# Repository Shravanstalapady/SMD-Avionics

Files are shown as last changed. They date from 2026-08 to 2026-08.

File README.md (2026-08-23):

# SMD-Avionics-PCB
# Sounding Rocket Avionics System

A complete avionics package for high-altitude sounding rockets, featuring dual redundancy in barometric sensing, real-time GPS/LoRa telemetry, and programmable pyro firing/servo control.

## Overview

This project implements a two-board avionics system for sounding rocket applications:

- **Flight Controller Board**: RP2350B-based main computer with integrated sensors and communication systems
- **Power Distribution Board**: Regulated power delivery with current monitoring and fault protection

The system is capable of logging sensor data to onboard storage, transmitting telemetry via LoRa, determining apogee via dual barometers, and firing pyro charges or deploying parachutes via servo control.



---

##  Hardware Architecture

### Flight Controller Board 

**Main Processor**
- Raspberry Pi RP2350B (QFN-80, dual-core ARM Cortex M33)
- 32 MHz crystal oscillator with load capacitors
- QSPI flash storage (W25Q128JVSIQ - 128Mb NOR flash)

**Inertial Measurement Unit (IMU)**
- LSM6DSO32 6-axis accelerometer + gyroscope (SPI interface)
- 3-axis acceleration and rotation rate measurement
- Can be used for apogee detection via vertical acceleration

**Barometric Sensors (Dual Redundancy)**
- Primary: BMP390 (SPI interface) - 300-1100 hPa range
- Secondary: MS5611 (I2C interface) - High altitude capable
- Cross-checked for data integrity and fallback capability

**GNSS/Positioning**
- L89HAS90 multi-constellation receiver
  - GPS, GLONASS, BeiDou, Galileo, IRNSS, QZSS support
  - 3D fix output, UTC time sync
  - External antenna via UFL connector

**Telemetry & Long-Range Communication**
- SX1262 LoRa module (868 MHz ISM band)
- SPI interface to MCU
- Real-time data transmission during flight

**Pyro & Servo Control**
- 4x pyro firing channels (continuity-enabled)
  - TLP281-4 optocouplers for isolation
  - IRLR7843 MOSFETs for power switching
  - continuity-check LEDs
- 2x servo PWM output channels
- 10kΩ pull-up resistors on signal lines

**Onboard Storage**
- SD card socket (QSPI quad mode capable)
- Data logging to microSD for black-box recording
- Shared SPI bus with accelerometer

**Interface & Debug**
- USB Type-C connector (CX90M-16P) for programming
- SWD debug header (SM03B-SRSS)
- Active piezo buzzer for audible feedback (GPIO control)
- 2x ARM debug LEDs (APT2012MGC, R0603 current limiting)
- 3x test points for oscilloscope probing (TP1-TP3)

**I2C & SPI Buses**
- I2C0: INA260 current monitor, Accelerometer(10kΩ pullups)
- SPI0: Primary barometer
- SPI1: SD card, MS5611
- QSPI: Flash memory

---

### Power Distribution Board (Main_FC_power_circuitary)

**Primary Buck Converter**
- TPS5450DDAR 5A adjustable regulator
  - Input: +BATT (Li-Po battery recommended)
  - Output: +5V at up to 5A
  - PA4343.153NLT inductor
  - Soft-start to limit inrush current

**Secondary Buck Converter**
- TLV62569PDDCR high-efficiency step-down
  - Input: +5V from primary converter
  - Output: +3.3V or other regulated voltage
  - Optimized for efficency.

**Current Monitoring**
- INA260AIPWR integrated power monitor
  - Measures input current and voltage in real-time
  - I2C interface to flight controller
  - Essential for battery health monitoring and power budgeting
  - Programmable alerts via ALERT pin

**Headers & Distribution**
- Multiple headers for connecting payloads
- +5V rail
- +5High rail
- +3.3V rail  
- Ground distribution (critical for low-impedance GND return)
- XT60 connector for external power
- Debug LEDs (3x) indicating power rail status

---

##  Interface Pinouts & Connectors

### Flight Controller - Key Signals

**GPS/GNSS (L89HAS90)**
- UART: RXD, TXD (async serial 9600 baud typical)
- 1PPS output for timing sync
- External antenna (RP-SMA via UFL)

**LoRa (SX1262)**
- SPI: MOSI, MISO, SCK, CS
- Control: DIO1, DIO2, RST, BUSY
- GPIO: TXEN, RXEN (optional Tx/Rx control)

**Servo Outputs**
- 2x 3-pin JST-PH headers (servo 1, servo 2)
  - Pin 1: +5V
  - Pin 2: PWM signal
  - Pin 3: GND

**Pyro Channels**
- 4x WAGO 2-pin push connectors (pyro 1-4 shared across 2 connectors)
- Electrical continuity check via onboard LEDs
- Fires on MCU GPIO command

**Debug/Serial**
- USB Type-C for programming & serial console
- SWD header (SWCLK, SWD, GND, 3.3V)

**Power Input**
- XT60 main battery connector
- +BATT and GND distribution rails between the two boards
  
**JST VH**
- Connect Power Board to Flight Computer Board
- +5, +3.3, +5H Power Rails, and data from INA Current Sensor is sent over.

---

##  Electrical Specifications

| Parameter | Value | Notes |
|---|---|---|
| **Battery Input** | 3S-4S Li-Po (11.1V - 14.8V nominal) | Connector: XT60 |
| **Board to board connectors** | 10A max per pin | Connector: JST VH |
| **+5V Rail** | 5A max @ 5V | Primary buck converter |
| **+3.3V Rail** | 2A max @ 3.3V | Secondary buck converter |
| **+1.1V Rail** | Internal only | For Rp2350 internal circuitary |
| **Temperature Range** | -40°C to +85°C | Component rated range |
| **SD Card Voltage** | 3.3V | Shared with MCU I/O |
| **LoRa Frequency** | 868 MHz ISM | Region-dependent; requires license compliance |
| **USB Power** | 500 mA max | For programming only; battery required for flight |

---

##  Features & Capabilities

### Sensor Capabilities
-  Dual redundant barometric altitude measurement  
-  6-axis IMU (acceleration + rotation rates)  
-  Multi-constellation GNSS positioning  
-  Real-time telemetry downlink (LoRa)  
-  Onboard data logging to SD card  

### Control & Firing
-  4 programmable pyro firing channels  
-  2 servo control outputs (PWM)  
-  Continuity monitoring on each pyro channel  
-  Optocoupler isolation for pyro firing  

### Power Management
-  Real-time current monitoring  
-  Multiple independent regulated rails  
-  Battery voltage monitoring  

### Interface & Diagnostics
-  USB programming & serial console  
-  SWD JTAG debug port  
-  Onboard status LEDs  
-  Piezo buzzer feedback  
-  Test points for scope probing  

---

##  Bill of Materials Summary

### Flight Controller Board
- **Microcontroller**: 1x RP2350B QFN-80
- **Sensors**: 2x barometers, 1x IMU, 1x GPS, 1x LoRa module
- **Power**: 2x buck converters, 20+ filtering capacitors
- **Discrete**: 30+ resistors, 10x diodes, 2x MOSFETs, 2x optocouplers
- **Connectors**: USB-C, SWD header, servo headers, pyro WAGO connectors, SD card socket
- **Total Components**: ~150 parts

### Power Distribution Board
- **Regulators**: TPS5450, TLV62569, INA260 current monitor
- **Input Protection**: Schottky diodes, XT60 connector
- **Debug**: 3x status LEDs with current-limiting resistors
- **Connectors**: Battery input, XT60 main output, JST VH
- **Total Components**: ~40 parts

Full BOM available in PDF schematics (see `/BOM` section).

---

##  Component Datasheets

Key datasheets for reference:
- **RP2350**: https://datasheets.raspberrypi.com/rp2350/rp2350-datasheet.pdf
- **BMP390**: https://www.bosch-sensortec.com/media/boschsensortec/downloads/datasheets/bst-bmp390-ds002.pdf
- **MS5611**: https://www.te.com/commerce/DocumentDelivery/DDEController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
- **LSM6DSO32**: https://www.st.com/content/st_com/en/products/motion-sensors/inemo-inertial-measurement-units/lsm6dso32.html
- **SX1262**: https://semtech.my.salesforce.com/sfc/p/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
- **L89HAS90**: https://www.u-blox.com/en/product/l89-high-precision-gnss-module





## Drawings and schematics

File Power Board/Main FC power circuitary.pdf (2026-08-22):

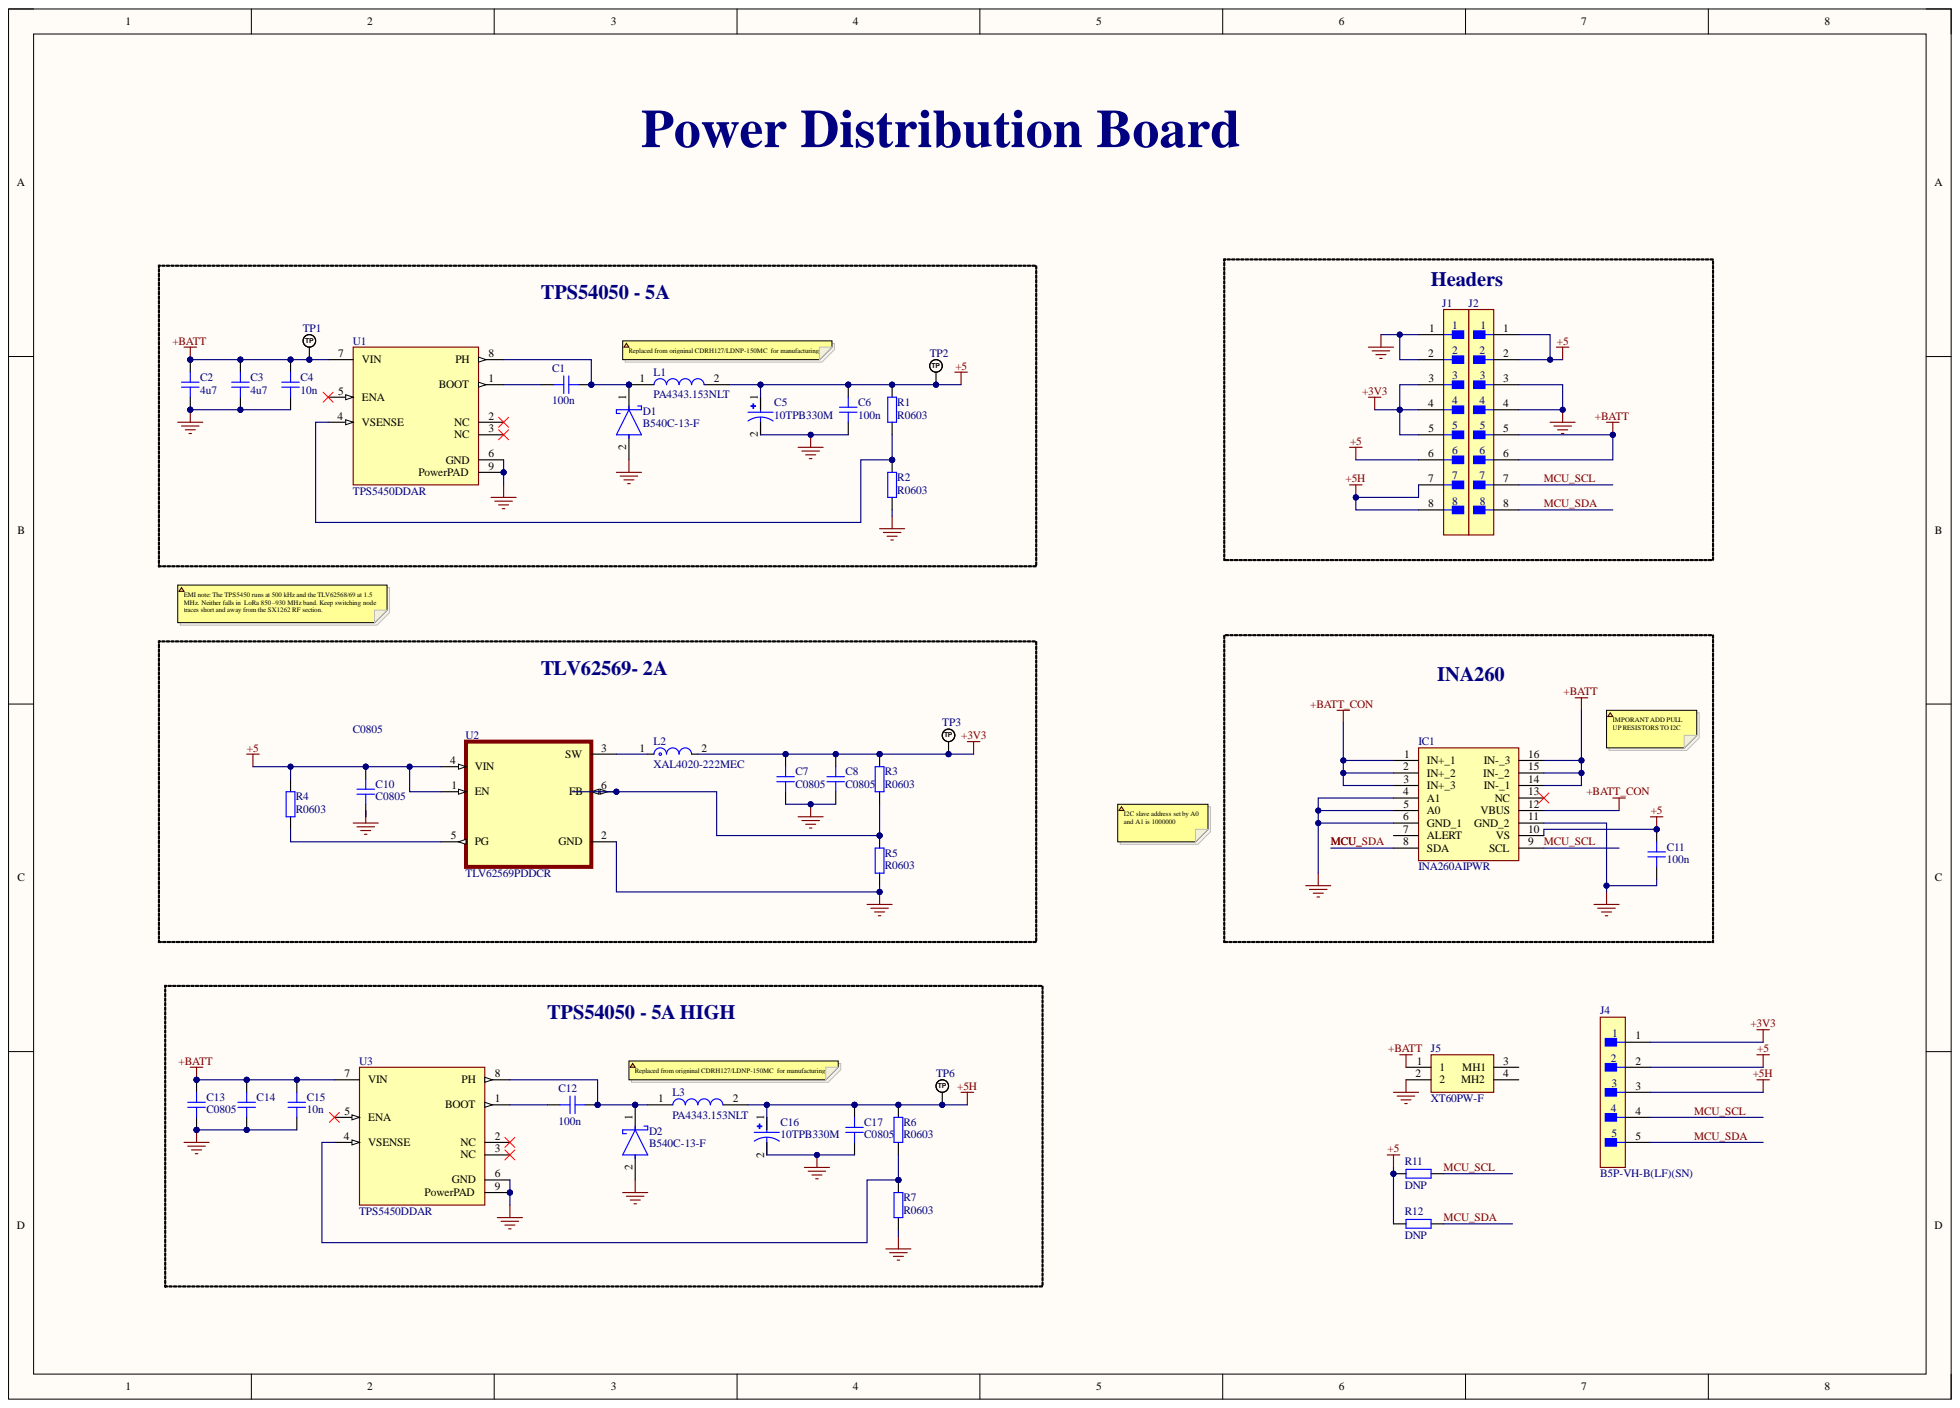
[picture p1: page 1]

Replaced from origninal CDRH127/LDNP-150MC for manufacturing

ENA 5

EMI note: The TPS5450 runs at 500 kHz and the TLV62568/69 at 1.5
MHz. Neither falls in LoRa 850 –930 MHz band. Keep switching node
traces short and away from the SX1262 RF section.

I2C slave address set by A0
and A1 is 1000000

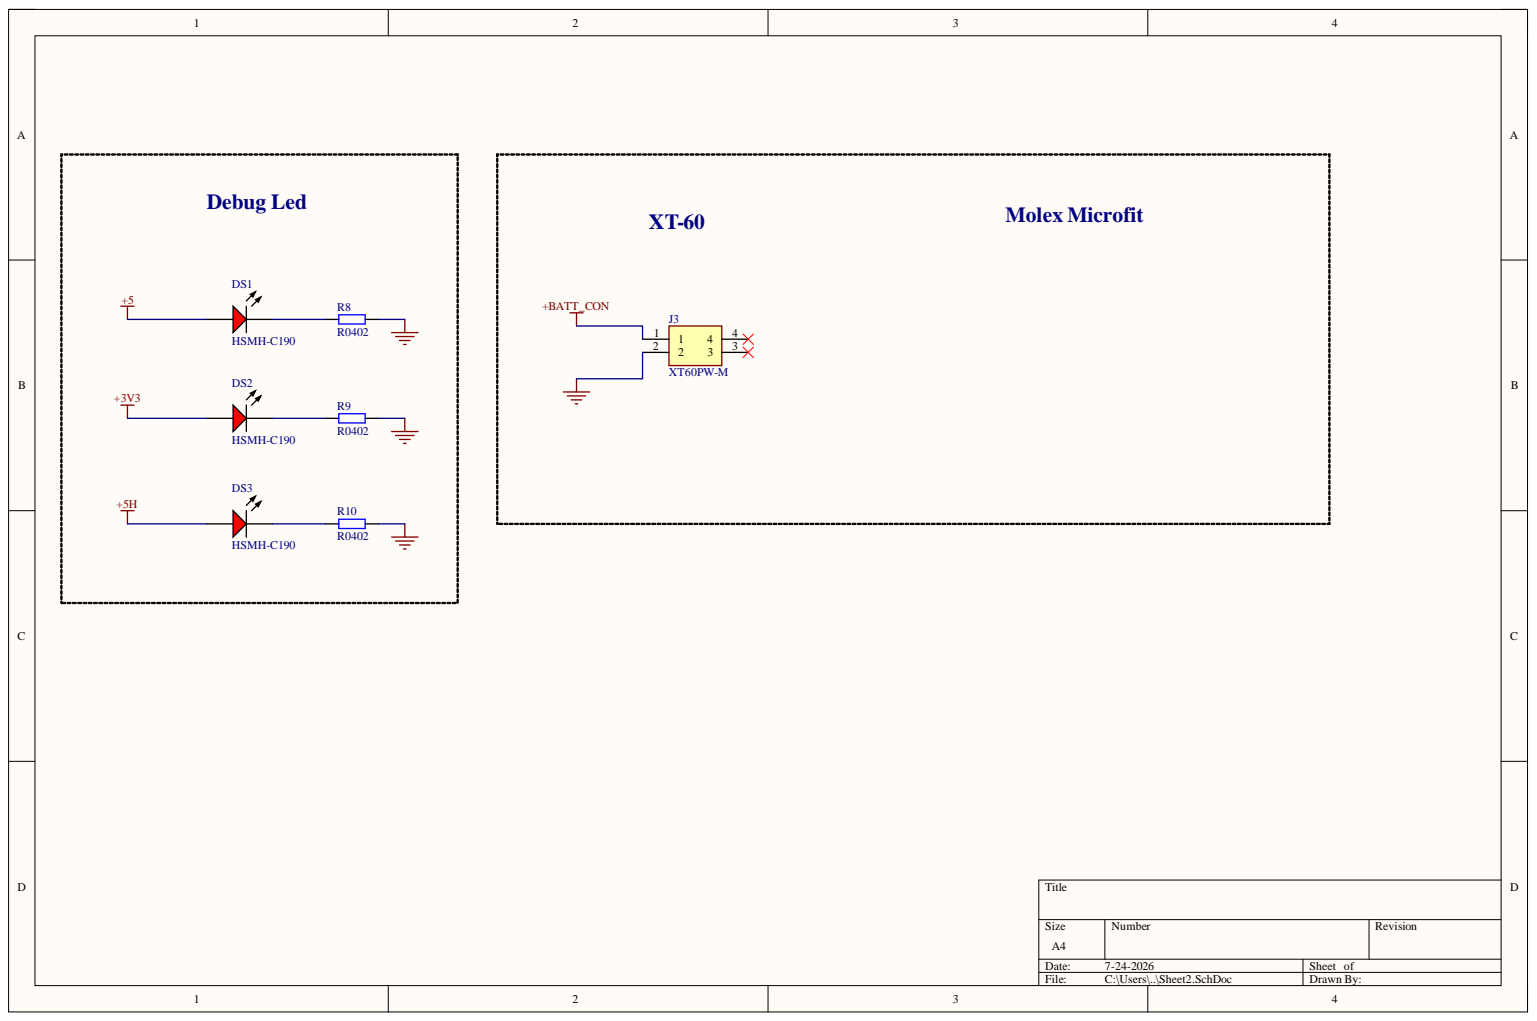
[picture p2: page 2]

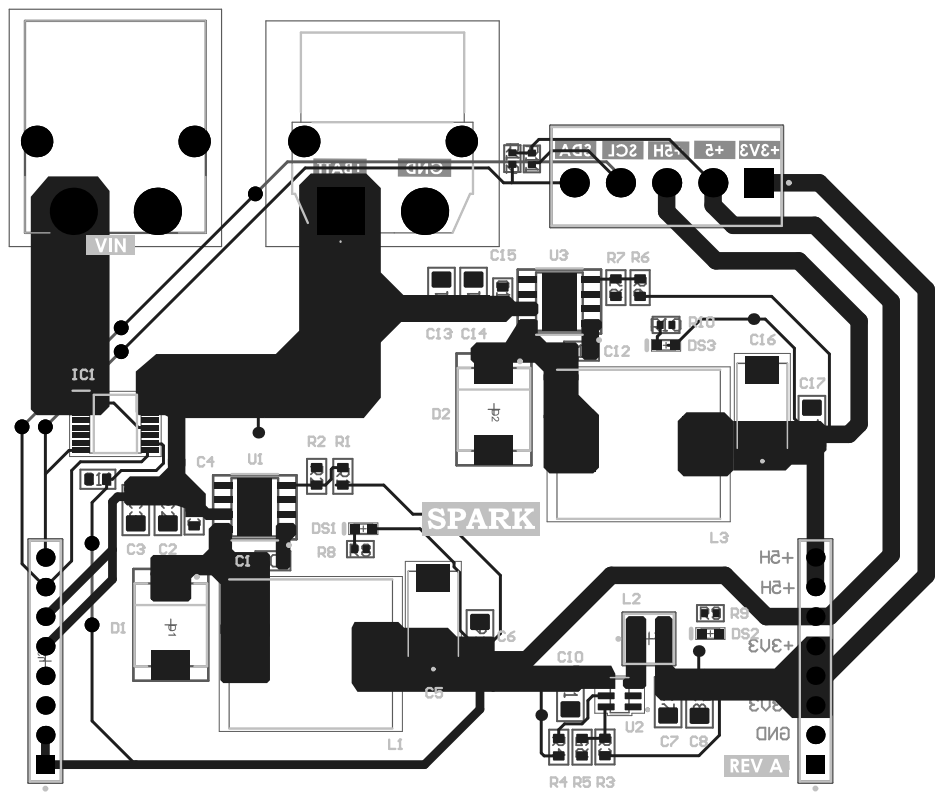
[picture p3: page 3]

Comment | Description | Designator | Footprint | LibRef | Quantity
100n | Capacitor SMD 0603 | C1, C11, C12 | CAP_0603 | CAP_0603 | 3
4u7 | Capacitor SMD 0805 | C2, C3 | CAP_0805 | CAP_0805 | 2
10n | Capacitor SMD 0603 | C4, C15 | CAP_0603 | CAP_0603 | 2
10TPB330M | | C5, C16 | CAP_10TPB330M | 10TPB330M | 2
100n | Capacitor SMD 0805 | C6 | CAP_0805 | CAP_0805 | 1
C0805 | Capacitor SMD 0805 | C7, C8, C10, C13, C14, C17 | CAP_0805 | CAP_0805 | 6
B540C-13-F | DIODE SCHOTTKY 40V 5A SMC | D1, D2 | FP-SMC-MFG | CMP-2000-05097-3 | 2
HSMH-C190 | LED Uni-Color Red, 65 mW, 20 mA, -40 to 85 degC, 2-Pin SMD, RoHS, Tape and Reel | DS1, DS2, DS3 | AVAG-HSMX-C190_V | CMP-007-00014-2 | 3
INA260AIPWR | Integrated Circuit | IC1 | SOP65P640X120-16N | INA260AIPWR | 1
TSW-108-08-G-S | CONN HEADER VERT 8POS 2.54MM | J1, J2 | FP-TSW-108-08-G-S-MFG | CMP-02766-000001-1 | 2
XT60PW-M | Connector | J3 | XT60PWM | XT60PW-M | 1
B5P-VH-B(LF)(SN) | CONN HEADER VERT 5POS 3.96MM | J4 | FP-B5P-VH-B_LF_SN-MFG | CMP-17439-000483-1 | 1
XT60PW-F | Connector | J5 | XT60PWF | XT60PW-F | 1
PA4343.153NLT | Inductor | L1, L3 | INDPM140128X650N | PA4343.153NLT | 2
XAL4020-222MEC | Fixed Inductors 2.2uH Shld 20% 5.5A 38.7mOhms AECQ2 | L2 | FP-XAL4020-MFG | CMP-11268-000134-1 | 1
R0603 | Resistor SMD 0603 | R1, R2, R3, R4, R5, R6, R7 | RES_0603 | RES_0603 | 7
R0402 | Resistor SMD 0402 | R8, R9, R10 | RES_0402 | RES_0402 | 3
DNP | Resistor SMD 0402 | R11, R12 | RES_0402 | RES_0402 | 2
TPS5450DDAR | IC REG BUCK ADJUSTABLE 5A 8SOPWR | U1, U3 | FP-DDA0008J-MFG | CMP-04918-000100-1 | 2
TLV62569PDDCR | 2.5V-5.5V input, 2-A high efficiency step-down buck converter in SOT23 and SOT563 package | U2 | SOT95P280X110-6N | TLV62569PDDCR | 1
